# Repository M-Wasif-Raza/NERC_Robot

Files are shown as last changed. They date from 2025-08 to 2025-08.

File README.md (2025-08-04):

# NERC 2024 Indigenous Robot - Autonomous Plantation Robot





🏆 Our team successfully secured first place in the Mini-NERC 2024 competition, demonstrating excellent capabilities in Robotics & Mechatronics doman.

<p align="center">
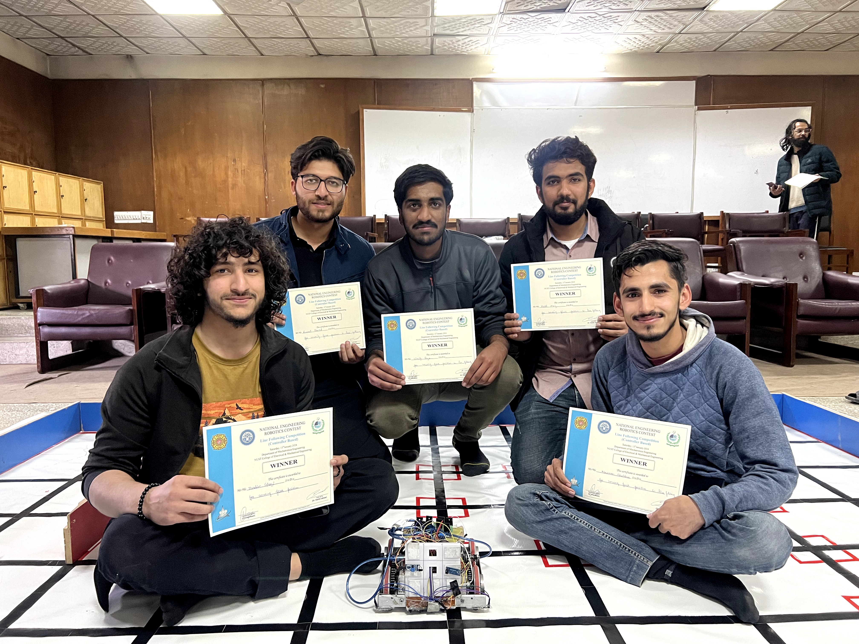
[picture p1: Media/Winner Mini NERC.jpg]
Team Photo
  
  <br/>
  <em>Winning team at Mini-NERC 2024</em>
</p>

<p align="center">
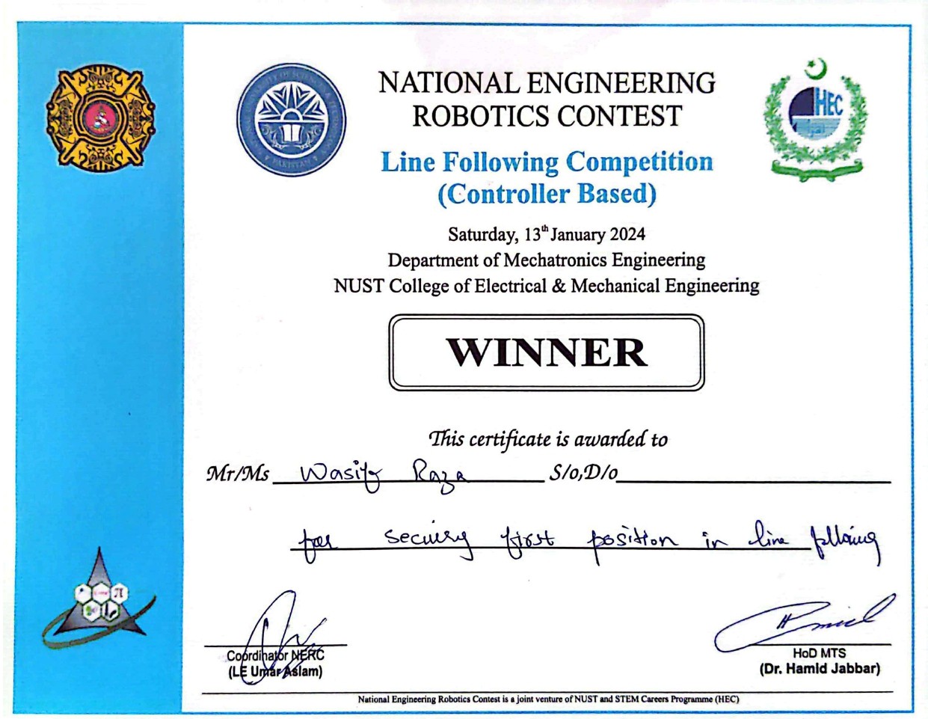
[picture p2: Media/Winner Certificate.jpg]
Winner Certificate
  
  <br/>
  <em>Winner Certificate</em>
</p>

---

##  Project Overview

### National Engineering Robotics Contest (NERC) 2024

The National Engineering Robotics Contest represents a collaborative initiative between the National University of Sciences and Technology (NUST) and the Higher Education Commission's STEM Careers Programme. NERC serves as Pakistan's premier platform for advancing robotics research and fostering innovation in autonomous systems.

### ❓ Problem Statement

The 2024 theme challenged teams to develop an autonomous robot capable of executing a complete tree plantation workflow:

**Primary Objectives:**
- Autonomous navigation through a structured farm environment
- Detection and removal of obstacles (rocks) from designated plantation areas
- Precise placement of trees in prepared soil locations
- Task completion within strict time and accuracy constraints

**Technical Requirements:**
- Fully autonomous operation with no human intervention
- Indigenous design and fabrication of all electronic systems
- Compliance with dimensional and weight specifications
- Integration of multiple sensor systems for navigation and object detection

### 🧱 Arena Specifications

The competition arena simulates a realistic agricultural environment:

- **Grid System**: 12×12 inch precision grid layout
- **Plantation Field**: Dedicated 3×3 grid area for tree placement
- **Dynamic Layout**: Randomized Rock & Tree placement across 9 possible positions
- **Navigation Aids**: Black line pathways and wall-mounted 2D position map

<p align="center">
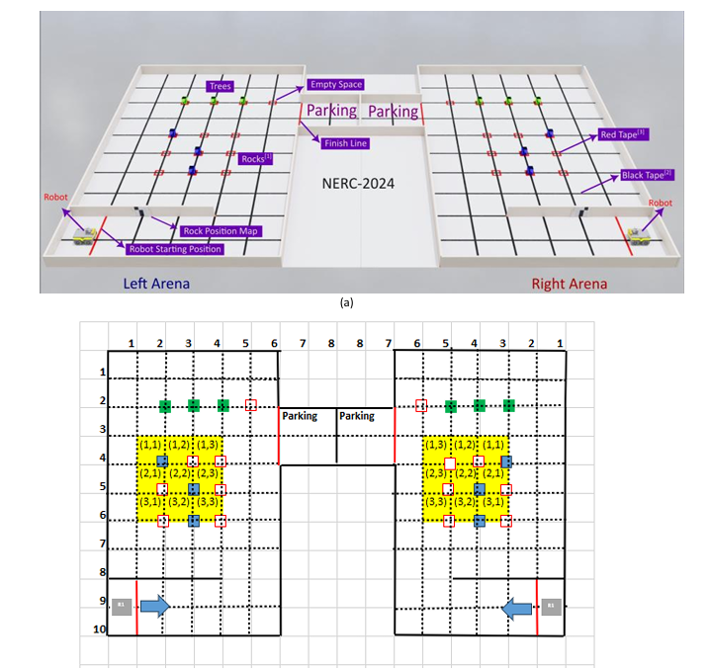
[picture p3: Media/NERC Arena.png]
  
  <br/>
  <em>Competition arena layout</em>
</p>

### 📐 Physical Constraints

| Parameter | Value |
|---|---|
| **Dimensions** | 10" × 10" × Variable Height | 
| **Weight** | < 12 kg | 

📌 For complete information about the competition theme, check [this](/NERC-2024%20Draft1.0.pdf).

---

## 🤖 Robot Overview

### Hardware Design

**Core System Components:**

| Component | Specification | Notes |
|---|---|---|
| **Microcontroller** | Arduino Mega (ATmega2560) | Increased I/O capability, more memory, suitable for complex robotics applications |
| **Sensor Array** | TCRT5000 IR Array (5-channel) | For Line Following |
| **Wheel Motor** | 24V DC Encoder Motors | Differential Drive Configuration |
| **Power System** | 25V LiPo Battery Pack | Alongwith Buck Convertor for Voltage Regulation |
| **Motor Control Circuit** | Custom H-Bridge Design | Indigenous category requirement |
| **Servo Motor** | MG996R Metal Gear Servo Motor | For lifting mechanism |

### Motor Control Circuit Design

The competition required designing a robust H-Bridge motor controller from discrete components.

**Design Specifications:**
- Bidirectional motor control with instant direction reversal
- PWM-based speed regulation
- 3A current capacity
- Arduino-compatible control interface

**Development Process:**
1. **Circuit Analysis**: Theoretical design validation using circuit simulation
2. **Prototype Testing**: Breadboard implementation and performance verification
3. **PCB Design**: Professional circuit board layout using Proteus software
4. **Manufacturing**: Self PCB fabrication and assembly

<p align="center">
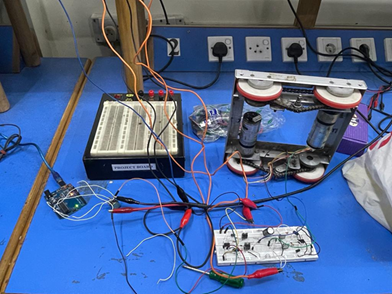
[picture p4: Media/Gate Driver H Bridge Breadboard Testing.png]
  
  <br/>
  <em>Circuit Testing</em>
</p>

### ⚙️ Mechanical System 

Structure of Robot Chassis 

<table align="center">
  <tr>
    <td align="center">
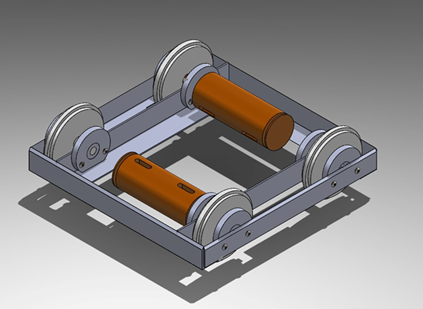
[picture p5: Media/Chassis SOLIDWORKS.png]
      <br/>
    </td>
    <td align="center">
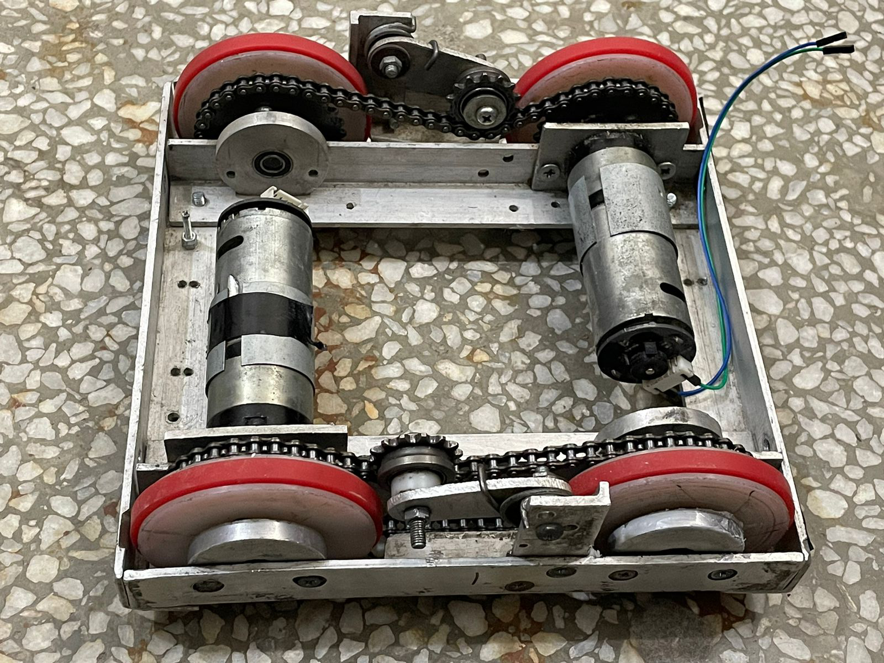
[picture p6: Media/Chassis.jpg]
      <br/>
    </td>
  </tr>
</table>

### 🔋 Power Management System

**Custom Battery Configuration:**
- **Cell Type**: 3.7V Lithium Polymer
- **Configuration**: 7-cell series arrangement (7S1P)
- **Capacity**: 4000mAh
- **Output Voltage**: 25.9V (nominal)

---

## 💻 Coding Development

### Development Process

1. **Hardware Setup**: Pin configuration and sensor/motor interface initialization
2. **Basic Motion Control**: Implementation of fundamental movement functions with encoder feedback
3. **Navigation System**: Development of line-following and turning algorithms using sensor arrays
4. **Task Automation**: Integration of object manipulation functions (pick/drop operations)
5. **System Testing**

### ⚡Function Overview

**Movement Control:**
- `goStraightAlign()`, `goback()`, `stop()` - Basic motion with differential speed control
- `rotateLeft()`, `rotateRight()`, `rotate180()` - Precision turns using encoder feedback
- `turnSlightlyLeft()`, `turnSlightlyRight()` - Line-following trajectory corrections

**Task Functions:**
- `pick()`, `drop()` – Automated manipulation with servo control  
- `map_reading()` – 2D map reading  

<br>

https://github.com/user-attachments/assets/2c020f59-3387-43c8-be6c-983f413f9202

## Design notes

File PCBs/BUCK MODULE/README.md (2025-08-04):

<p align="center">
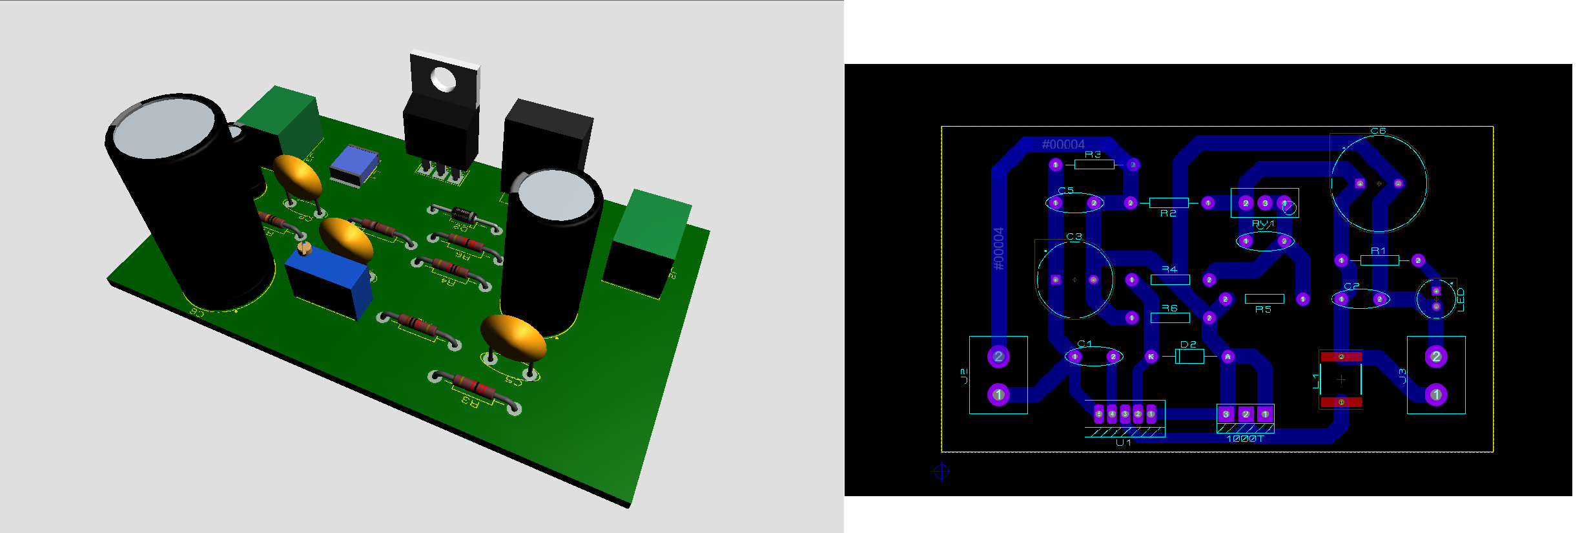
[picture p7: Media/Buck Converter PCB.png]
Winner Certificate
  
</p>

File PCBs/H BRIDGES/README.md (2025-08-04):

## H-Bridge using Gate Driver IC

<p align="center">
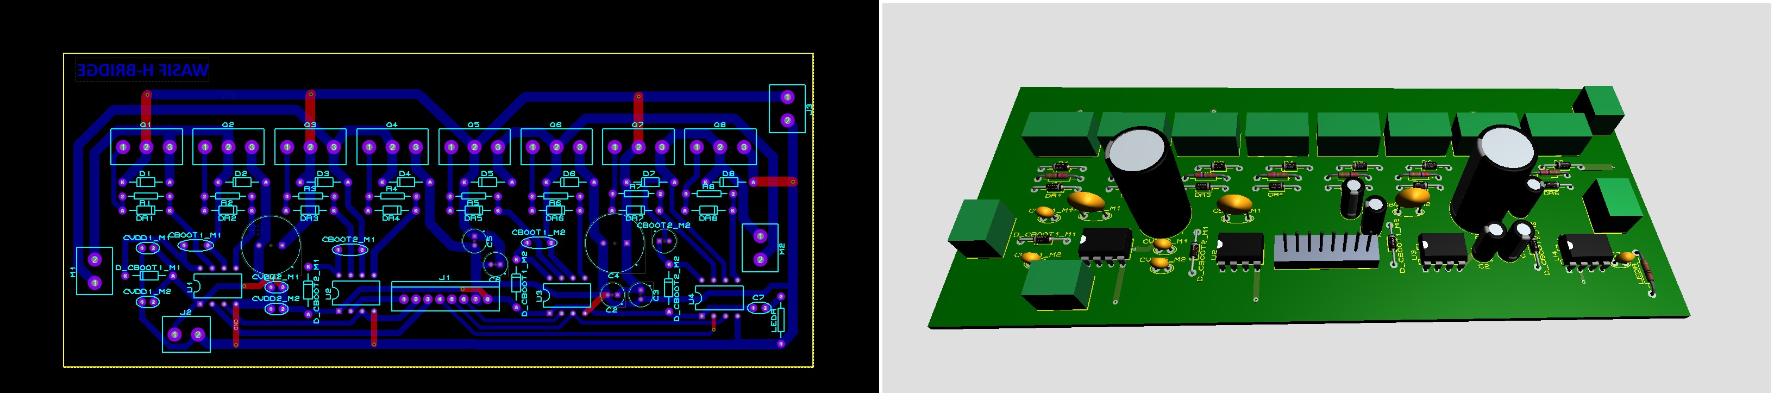
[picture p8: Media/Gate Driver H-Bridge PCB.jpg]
  
</p>
<p align="center">
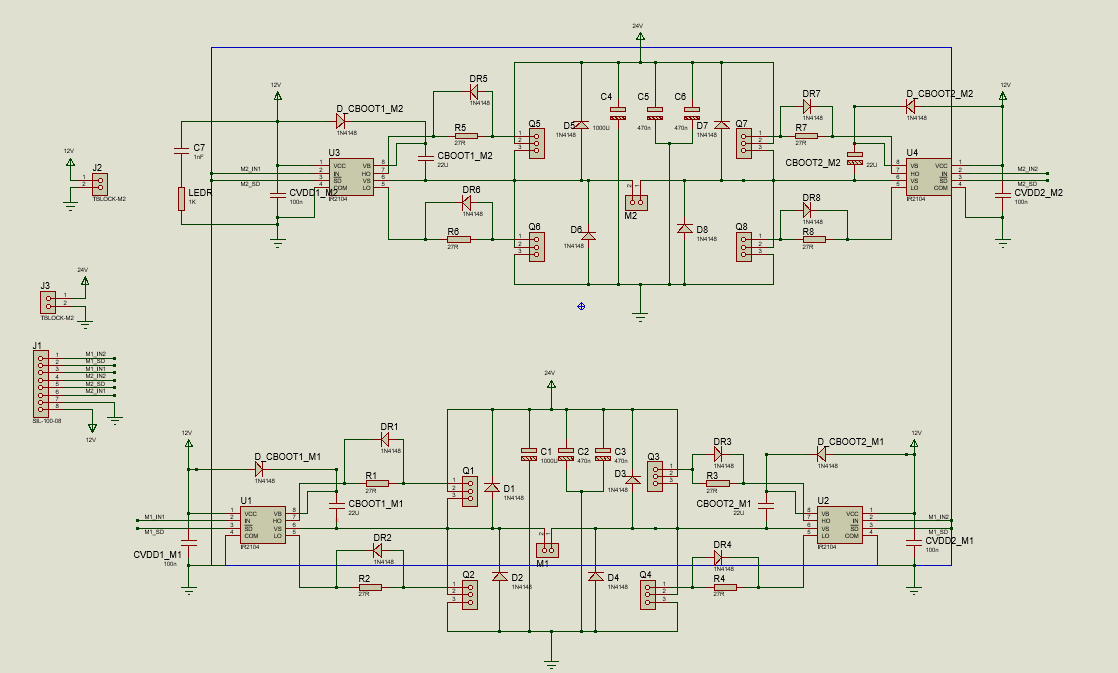
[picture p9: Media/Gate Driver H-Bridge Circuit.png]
  
</p>

## TIP-Based H-Bridge
<p align="center">
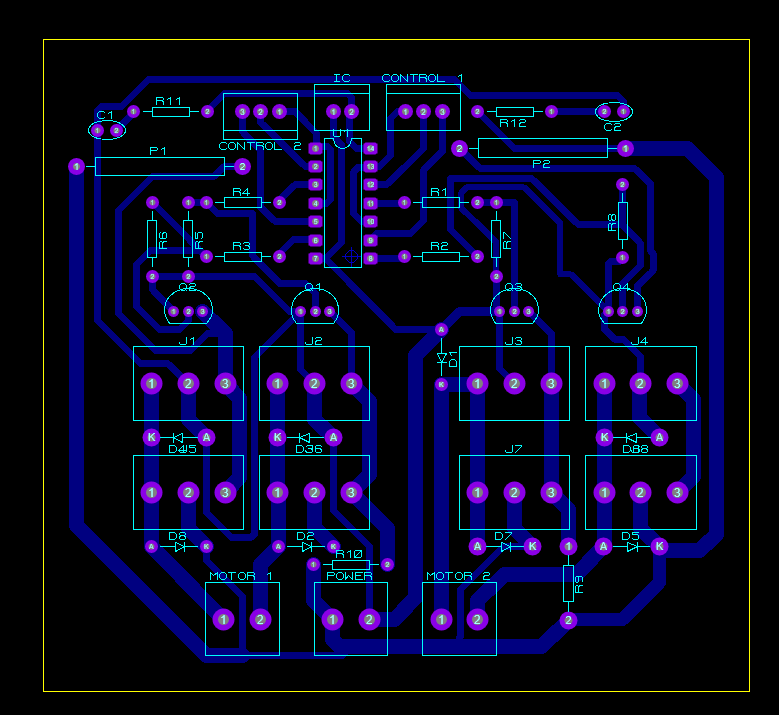
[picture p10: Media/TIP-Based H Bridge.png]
  
</p>

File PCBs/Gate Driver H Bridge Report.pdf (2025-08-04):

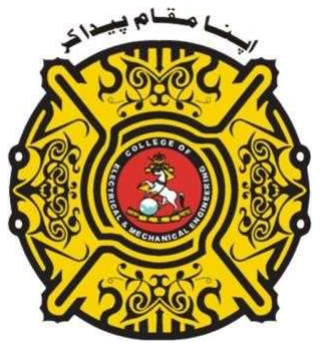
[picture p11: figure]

1

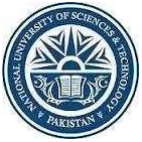
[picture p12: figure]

# Electronic Design Circuit

(EE-313)

# DE-43 Mechatronics Syndicate –B

## Project report

## H-Bridge Motor Driver for 24V, 2-5A DC Motor

## Names:

1. Muhammad Wasif Raza | 385589
2. Rameel Ahmed | 390647
3. Abdul Moiz | 392858

Submitted to: LE Noor ul Huda

2

## Table of Contents

1.Introducon | 1

### 1.1 Background | 2 1.2 Objectives | 3

2.Literature Review | 4
3.Circuit Design | 1

### 3.1 Motor Specifications | 2 3.2 H-Bridge Configuration | 3 3.3 Component Selection | 2 3.4 Power Supply | 3

4.Calculaons | 4

### 4.1 Current Ratings | 5 4.2 Power Dissipation | 6

5.Implementaon | 1

### 5.1 Circuit Assembly | 2 5.2 Testing Procedures | 3

6.Results and Discussion | 4

### 6.1 Experimental Results | 5 6.2 Performance Evaluaon | 6

7.Conclusion | 1
8.Future Work | 4
9.References | 1

3

## 1. Introducon:

### 1.1 Background:

H-Bridge motor drivers are crucial components in electronic systems that require bidireconal control of DC motors. They consist of a configuraon of switches (typically transistors) that enable the motor to move both forward and backward. This flexibility is essenal in applicaons such as robocs, electric vehicles, and industrial automaon.

### 1.2 Objecves:

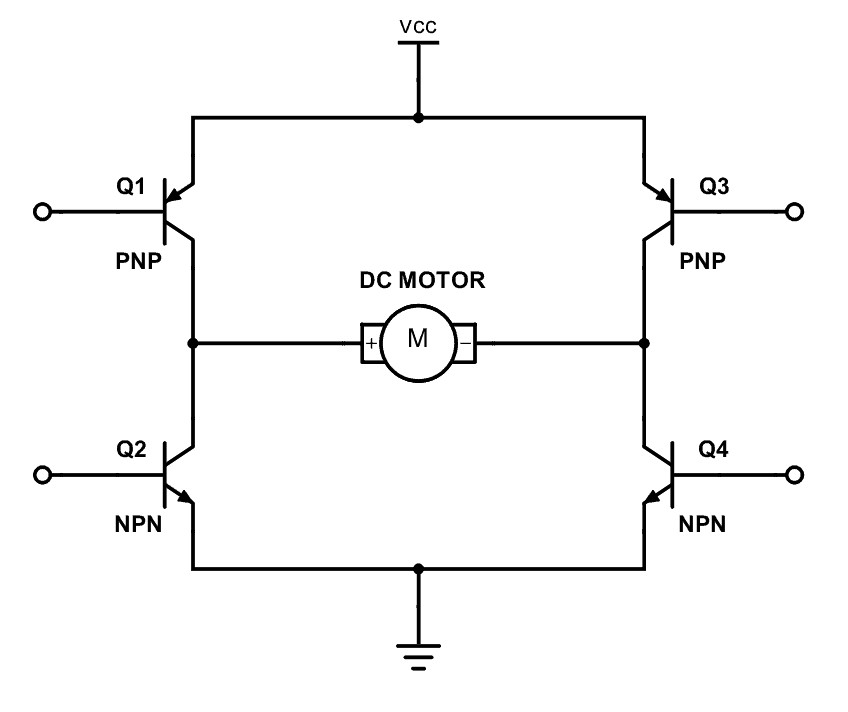
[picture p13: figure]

The primary goal of this project was to design and implement an efficient H-Bridge motor driver capable of controlling a 24V DC motor. The driver should enable bidireconal moon with a current rang suitable for motors ranging from 2 to 5 amperes which we have achieved in this project.

## 2. Literature Review:

H-Bridge motor drivers have been extensively studied and widely applied in various fields. PWM (Pulse Width Modulaon) is oen employed to control motor speed efficiently. MOSFETs are commonly used as switching elements due to their fast-switching speeds and low power consumpon. Safety consideraons involve protecng the circuit from overcurrent and overvoltage condions to prevent damage to the components.

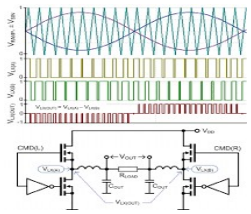
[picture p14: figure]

4

## 3. Circuit Design:

### 3.1 Motor Specificaons:

The 24V DC motor in queson has the following specificaons: operang voltage of 24V, current rang ranging from 2 to 5 amperes, and a power rang of [average=80-120W]. These specificaons will guide the design of the H-Bridge circuit.

### 3.2 H-Bridge Configuraon:

The chosen H-Bridge configuraon involves four MOSFETs arranged in a bridge topology. The schemac diagram illustrates how these components enable bidireconal control of the connected DC motor. Diodes are placed across each MOSFET to handle back-EMF and protect the transistors.

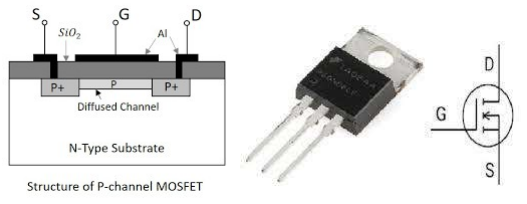
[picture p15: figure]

### 3.3 Component Selecon:

MOSFETs with suitable voltage and current rangs have been selected for this project ([provide specific part numbers]). The diodes should have fast recovery mes to handle the motor's inducve loads effecvely. Addionally, resistors are chosen to set gate drive currents and ensure proper MOSFET switching.

### 1. MOSFETs (Metal-Oxide-Semiconductor Field-Effect Transistors):

- N-channel MOSFETs -4x [IRF-3205]

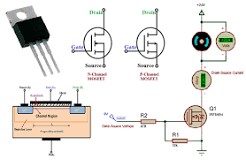
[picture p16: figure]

5

### 2. Diodes:

- Fast-recovery diodes (4x 1N-4148,6x 1N-5819)

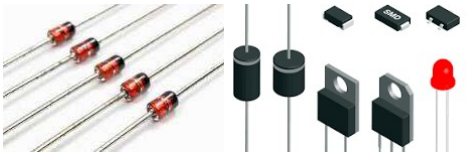
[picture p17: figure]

### 3. Resistors:

- Gate resistors for MOSFETs (4x 27ohm)

### 4. Capacitors:

- Bootstrap capacitors for MOSFET gate drivers [2x 1 uF]

### 5. Power Supply:

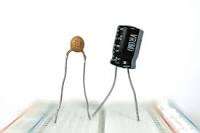
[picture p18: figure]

- Vcc: Power supply for the H-Bridge circuit (Select based on voltage and current requirements)

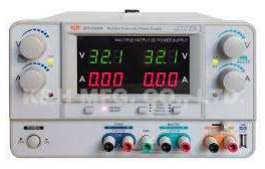
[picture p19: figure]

6

### 6. DC Motor:

- 24V DC Motor with a current rang between 2-5 amperes

### 7. Heat Sink:

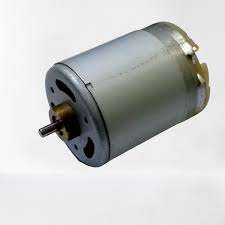
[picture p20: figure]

- Heat sinks for MOSFETs to dissipate heat generated during operaon

### 8. Connectors and Wiring:

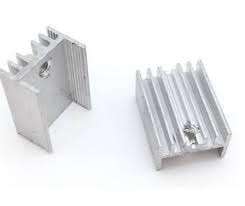
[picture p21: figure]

- Connectors and wiring for power supply, motor connecons, and control signals.

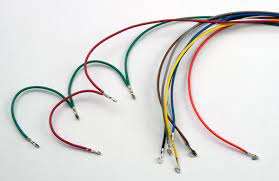
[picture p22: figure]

7

### 9. PCB(Printed Circuit Board)

- PCB to mount and connect all components.

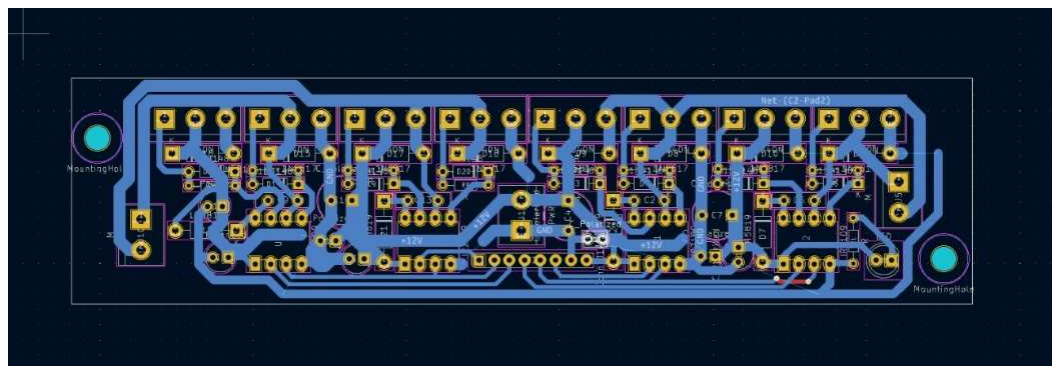
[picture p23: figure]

### 3.4 Power Supply:

The power supply for the H-Bridge circuit must provide a stable voltage in the range of [0-24] V. Consideraons for voltage regulaon and filtering are essenal to maintain stable operaon.

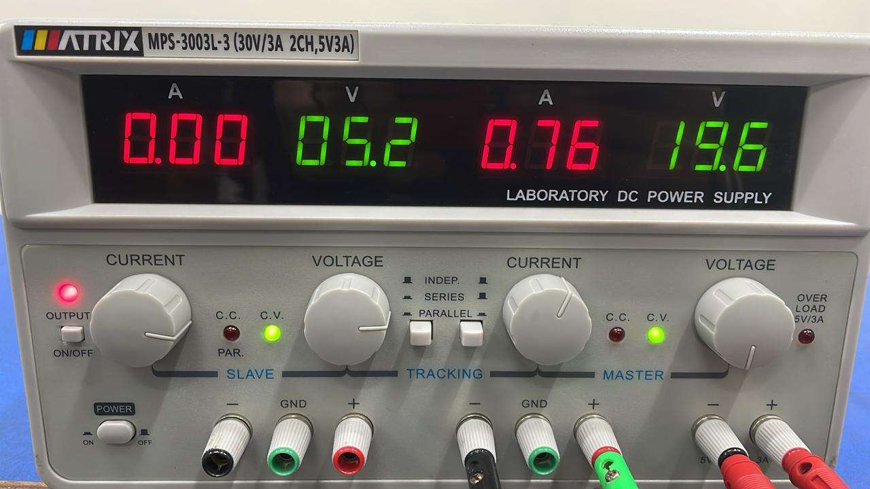
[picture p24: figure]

8

## 4. Calculaons:

### 4.1 Current Rangs:

Calculaons are performed to determine the current rangs of the MOSFETs and diodes. The peak current through each MOSFET is calculated as [2-5]A. Diode currents are evaluated to ensure they can handle the back-EMF generated by the motor.

### 4.2 Power Dissipaon:

Power dissipaon calculaons are crucial for determining the thermal requirements of the MOSFETs and diodes. This involves evaluang the power dissipated during the ON and OFF states of the transistors.

## 5. Implementaon:

### 5.1 Circuit Assembly:

Follow these steps to assemble the H-Bridge circuit:
1. Place the MOSFETs and diodes on the PCB according to the schemac.
2. Connect the gate, source, and drain terminals of the MOSFETs appropriately.
3. Ensure proper placement of diodes to handle back-EMF.
4. Connect the power supply and motor as per the schemac.

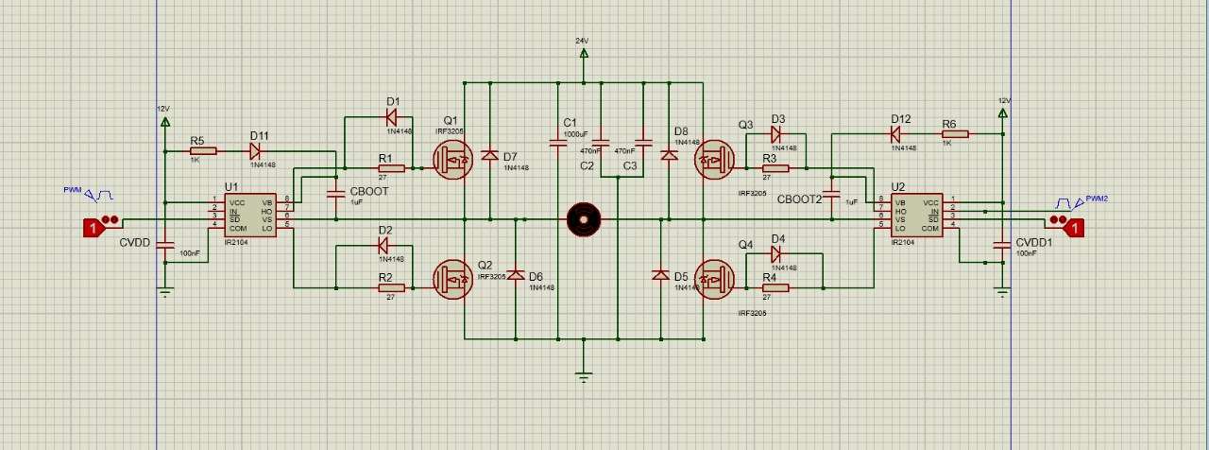
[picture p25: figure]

### 5.2 Tesng Procedures:

Tesng involves the following steps:
1. Apply power and verify that there are no short circuits.
2. Test forward and reverse moon using PWM for speed control.
3. Monitor current and voltage waveforms on an oscilloscope.
4. Ensure that the driver operates within safe temperature limits.

9

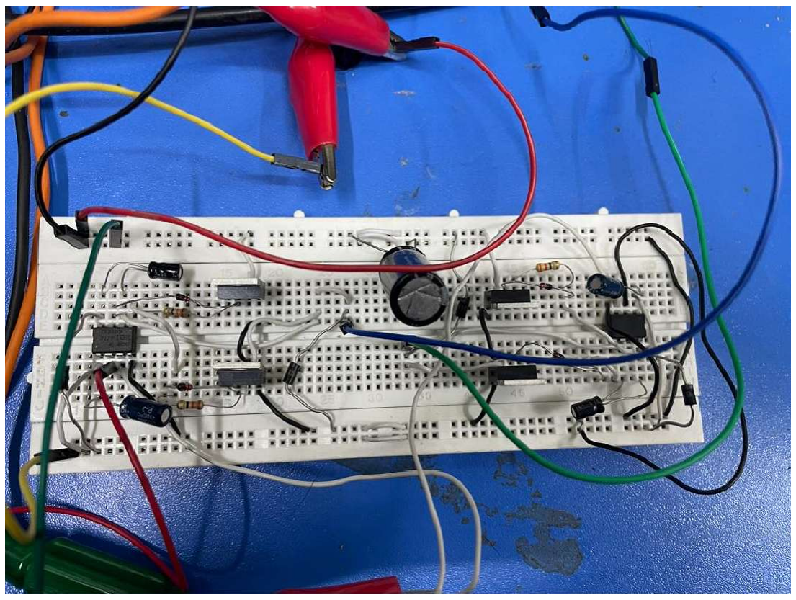
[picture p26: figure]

## 6. Results and Discussion:

### 6.1 Experimental Results:

Experimental results confirm the successful bidireconal control of the 24V DC motor. Speed control using PWM is effecve, and the driver operates within the specified current limits. Voltage and current waveforms exhibit expected behaviours.

### 6.2 Performance Evaluaon:

The H-Bridge motor driver performs well, meeng the project objecves. The efficiency of the bidireconal control and the ability to handle the specified current range are confirmed. Comparisons between theorecal calculaons and experimental results show good agreement.

## 7. Conclusion:

In conclusion, the designed H-Bridge motor driver effecvely controls a 24V DC motor bidireconally. The project has successfully achieved its objecves, providing a reliable and efficient soluon for applicaons requiring versale motor control.

10

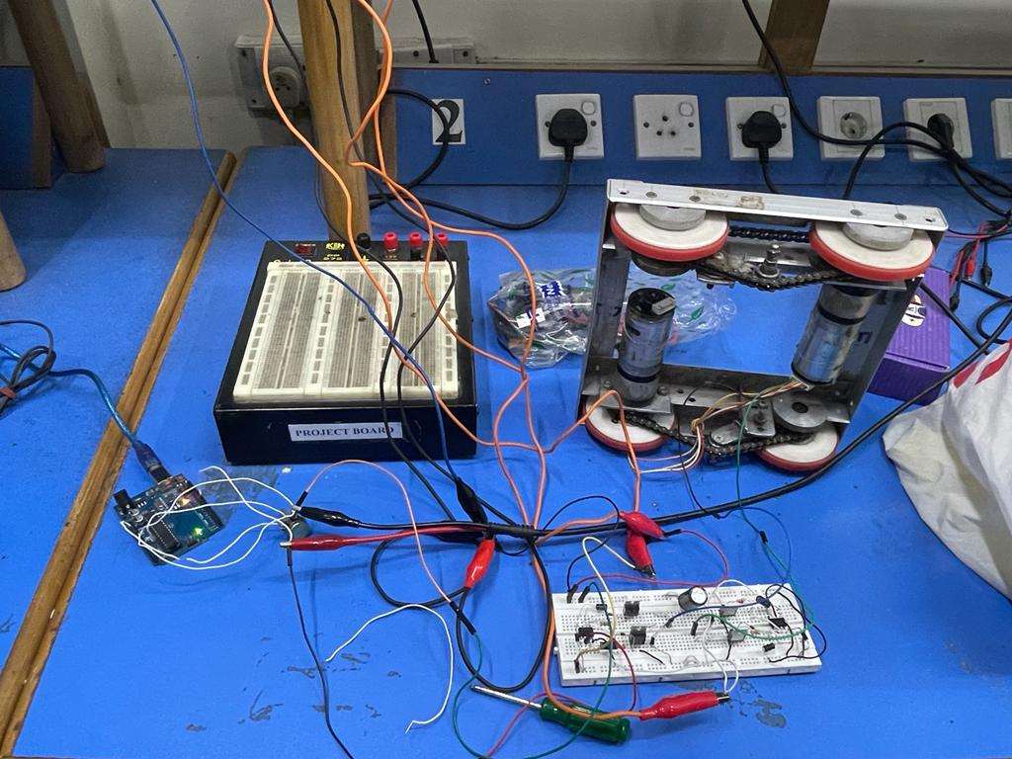
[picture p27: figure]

## 8. Future Work:

Potenal areas for improvement include making a dual pcb on a single board.

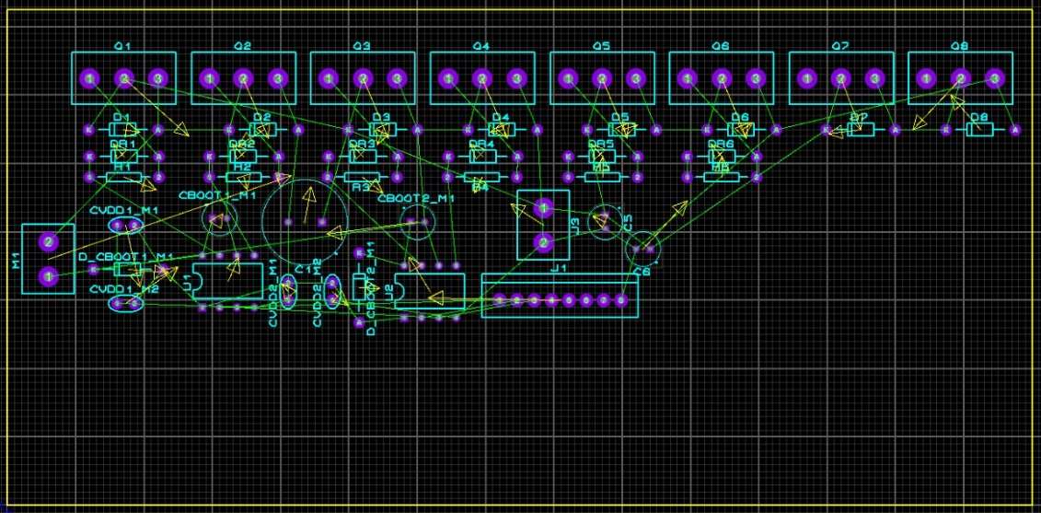
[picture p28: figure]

## 9. References:

### 1. hps://www..com/lit/an/slua887a/slua887a.pdf?ts=1701760089734&ref_url=hps%253

A%252F%252Fwww.google.com%252F

### 2. hps://pdf1.alldatasheet.com/datasheet-pdf/view/398486/IRF/IR2109.html 3. hps://www.hindawi.com/journals/je/2022/2273819/

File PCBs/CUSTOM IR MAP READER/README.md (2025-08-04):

<p align="center">
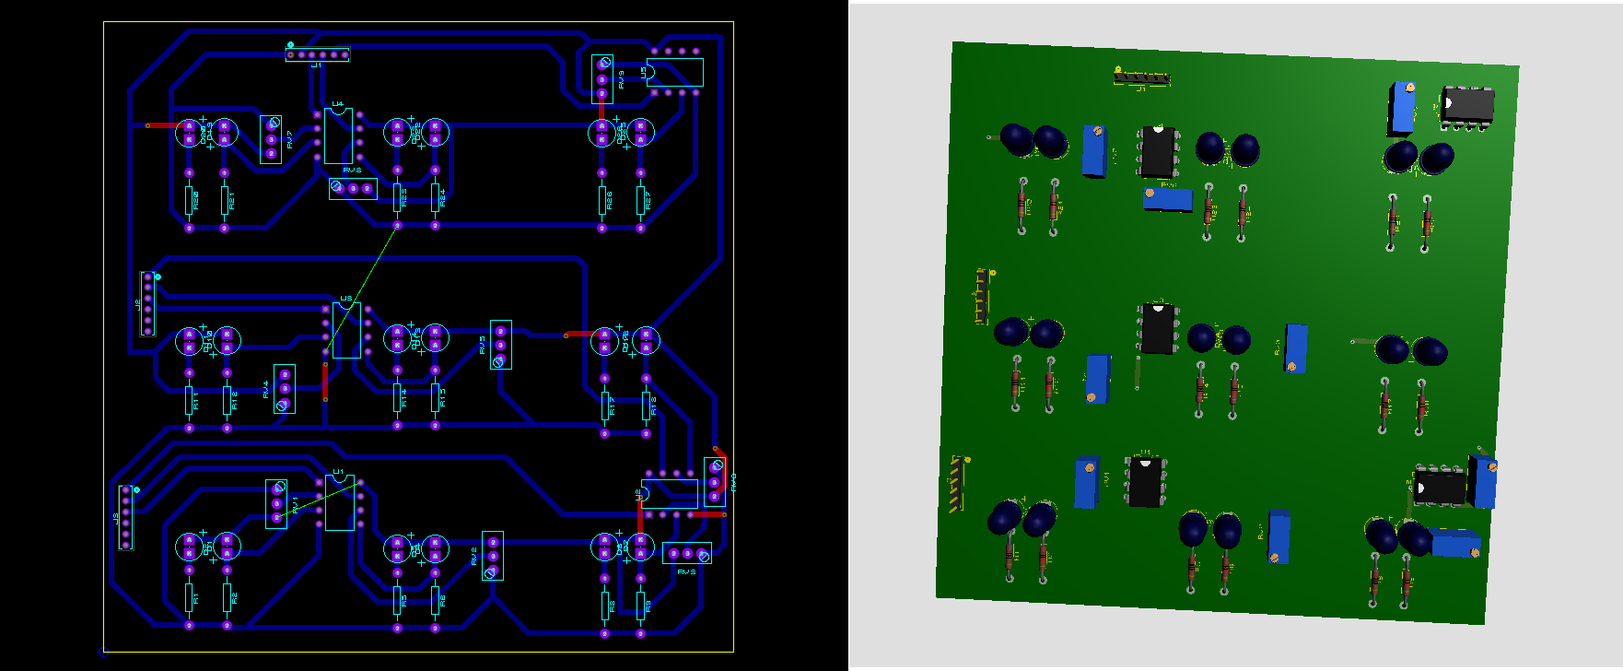
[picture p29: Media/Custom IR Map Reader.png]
Winner Certificate
  
</p>

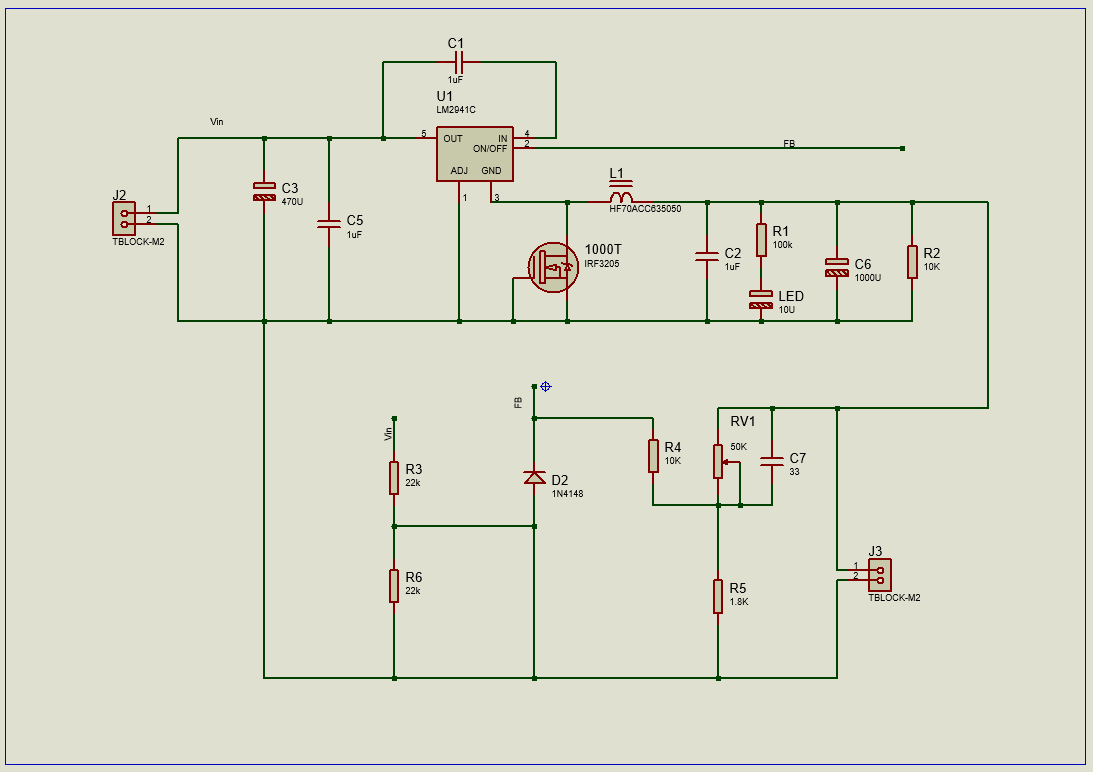
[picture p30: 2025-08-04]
Media/Buck Converter Circuit.png

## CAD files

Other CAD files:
PCBs/CUSTOM IR MAP READER/SOLIDWORKS FILE/Board.SLDPRT

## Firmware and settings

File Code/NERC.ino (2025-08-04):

#include <Encoder.h>
#include <Servo.h>

Servo myservo; 
int pos = 65;
// Define the pins for the encoders
#define ENCODER1_A 2
#define ENCODER1_B 5
#define ENCODER2_A 3
#define ENCODER2_B 4

// Define the pins for the motor control
#define L_in1 42// LEFT MOTOR
#define L_in2 43 // LEFT MOTOR reverse
#define R_in1 40 // right MOTOR
#define R_in2 41// RIGHT MOTOR reverse
#define LEFT_Motor_PWM 7
#define RIGHT_Motor_PWM 6

// Define the pins for the sensors
#define MS 23 // right MOTOR
#define RS 24
#define RRS 25
#define LS 26
#define LLS 27
#define S1 28
#define S2 29
#define LBACK 36
#define RBACK 37
#define LMBACK 34
#define RMBACK 35

int map_arr[] = {48,46,47,
                 49,51,50};
                 
int map_arr_value[6];

int pulsel=0;
int pulser=0;
// Create instances of the Encoder class
Encoder encoder1(ENCODER1_A, ENCODER1_B);
Encoder encoder2(ENCODER2_A, ENCODER2_B);
int counter= -2;
int lspd=160;
int rspd=160;
int ll=210;
int rr=210;
int stop_forward_speed=110;

void setup() 
{ // Set motor control pins as outputs
  Serial.begin(9600);
  pinMode(R_in1, OUTPUT);
  pinMode(L_in2, OUTPUT);
  pinMode(R_in2, OUTPUT);
  pinMode(L_in1, OUTPUT);
  pinMode(LEFT_Motor_PWM, OUTPUT);
  pinMode(RIGHT_Motor_PWM, OUTPUT);
  // Set all of the sensor pins to inputs
  pinMode(LS, INPUT);
  pinMode(LLS, INPUT);
  pinMode(RS, INPUT);
  pinMode(RRS, INPUT);
  pinMode(MS,INPUT);
  pinMode(S1,INPUT);
  pinMode(S2,INPUT);
  pinMode(RBACK,INPUT);
  pinMode(LBACK,INPUT);
  for(int i = 0;i<6;i++)
  {
    pinMode(map_arr[i],INPUT);
  }
  myservo.attach(10);
  // Servo is stationary.
  myservo.write(100);
}

void rotate180(int a, int b)
{
  stop();
  delay(500);
// Move motor 1 forward
  encoder1.write(0);
  encoder2.write(0);
  int encoder_L = encoder2.read();
  int encoder_R = encoder1.read();
  int middleSensor = digitalRead(MS);

  while(encoder_R<2050&&encoder_L>-2050)
  {
    digitalWrite(R_in2, LOW);
    digitalWrite(R_in1,HIGH);
    digitalWrite(L_in2, HIGH);
    digitalWrite(L_in1, LOW);
    analogWrite(LEFT_Motor_PWM, a);
    analogWrite(RIGHT_Motor_PWM, b);
    encoder_L = encoder2.read();
    encoder_R = encoder1.read();
  }
  while(encoder_L>-2050)
  {
    digitalWrite(R_in2, LOW);
    digitalWrite(R_in1,LOW);
    digitalWrite(L_in2,HIGH);
    digitalWrite(L_in1, LOW);
    analogWrite(LEFT_Motor_PWM, a);
    analogWrite(RIGHT_Motor_PWM, b);
    encoder_L = encoder2.read();
    encoder_R = encoder1.read();
  }
  while(encoder_R<2050)
  {
    digitalWrite(R_in2, LOW);
    digitalWrite(R_in1,HIGH);
    digitalWrite(L_in2, LOW);
    digitalWrite(L_in1, LOW);
    analogWrite(LEFT_Motor_PWM, a);
    analogWrite(RIGHT_Motor_PWM, b);
    encoder_L = encoder2.read();
    encoder_R = encoder1.read();
  }

  pulsel=encoder1.read();
  pulser=encoder2.read();
  Serial.print("Pulse left Count: " );
  Serial.println(pulsel);
  Serial.print("Pulse right Count: " );
  Serial.println(pulser);
  encoder1.write(0);
  encoder2.write(0);
   encoder_L = encoder2.read();
   encoder_R = encoder1.read();
  
  while(encoder_L<50 && encoder_R<50 )
  {
    digitalWrite(R_in2, LOW);
    digitalWrite(R_in1, HIGH);
    digitalWrite(L_in2, LOW);
    digitalWrite(L_in1, HIGH);
    analogWrite(LEFT_Motor_PWM, stop_forward_speed);
    analogWrite(RIGHT_Motor_PWM, stop_forward_speed);
    encoder_L = encoder2.read();
    encoder_R = encoder1.read();
  }
  stop();  
}

void rotateRight11(int a, int b)
{
  stop();
  delay(300);

  encoder1.write(0);
  encoder2.write(0);
  int encoder_L = encoder2.read();
  int encoder_R = encoder1.read();
  
  while(encoder_L<250 && encoder_R<250)
  {
    digitalWrite(R_in2, LOW);
    digitalWrite(R_in1, HIGH);
    digitalWrite(L_in2, LOW);
    digitalWrite(L_in1, HIGH);
    analogWrite(LEFT_Motor_PWM, stop_forward_speed);
    analogWrite(RIGHT_Motor_PWM, stop_forward_speed);
    encoder_L = encoder2.read();
    encoder_R = encoder1.read();
  }

  encoder1.write(0);
  encoder2.write(0);
  encoder_L = encoder2.read();
  encoder_R = encoder1.read();
  int rightSensor = digitalRead(RS);

  while(encoder_L<1050 && encoder_R>-950 )
  {
    digitalWrite(R_in2, HIGH);
    digitalWrite(R_in1, LOW);
    digitalWrite(L_in2, LOW);
    digitalWrite(L_in1, HIGH);
    analogWrite(LEFT_Motor_PWM, a);
    analogWrite(RIGHT_Motor_PWM, b);
    encoder_L = encoder2.read();
    encoder_R = encoder1.read();
    rightSensor = digitalRead(RS);
  }
  while(encoder_R>-950 )
  {
    digitalWrite(R_in2, HIGH);
    digitalWrite(R_in1, LOW);
    digitalWrite(L_in2, LOW);
    digitalWrite(L_in1, LOW);
    analogWrite(LEFT_Motor_PWM, a);
    analogWrite(RIGHT_Motor_PWM, b);
    encoder_L = encoder2.read();
    encoder_R = encoder1.read();
  }
  while(encoder_L<1050)
  {
    digitalWrite(R_in2, LOW);
    digitalWrite(R_in1, LOW);
    digitalWrite(L_in2, LOW);
    digitalWrite(L_in1, HIGH);
    analogWrite(LEFT_Motor_PWM, a);
    analogWrite(RIGHT_Motor_PWM, b);
    encoder_L = encoder2.read();
    encoder_R = encoder1.read();
  }
  stop();
  pulser=encoder1.read();
  pulsel=encoder2.read();
  Serial.print("Pulse left Count: " );
  Serial.println(pulsel);
  Serial.print("Pulse right Count: " );
  Serial.println(pulser);
}

void rotateRight(int a, int b)
{
  stop();
  delay(350);
  int L_MS = digitalRead(S1);
  int R_MS = digitalRead(S2);
  
  while(R_MS==1 && L_MS == 1)
  {
    goStraightAlign(stop_forward_speed,stop_forward_speed);
    L_MS = digitalRead(S1);
    R_MS = digitalRead(S2);
  }

  encoder1.write(0);
  encoder2.write(0);
  int encoder_L = encoder2.read();
  int encoder_R = encoder1.read();
  
  /*while(encoder_L<10 && encoder_R<10 )
  {
    digitalWrite(R_in2, LOW);
    digitalWrite(R_in1, HIGH);
    digitalWrite(L_in2, LOW);
    digitalWrite(L_in1, HIGH);
    analogWrite(LEFT_Motor_PWM, stop_forward_speed);
    analogWrite(RIGHT_Motor_PWM, stop_forward_speed);
    encoder_L = encoder2.read();
    encoder_R = encoder1.read();
  }*/

  encoder1.write(0);
  encoder2.write(0);
  encoder_L = encoder2.read();
  encoder_R = encoder1.read();
  int rightSensor = digitalRead(RS);

  while(encoder_L<500 && encoder_R>-500 )
  {
    digitalWrite(R_in2, HIGH);
    digitalWrite(R_in1, LOW);
    digitalWrite(L_in2, LOW);
    digitalWrite(L_in1, HIGH);
    analogWrite(LEFT_Motor_PWM, a);
    analogWrite(RIGHT_Motor_PWM, b);
    encoder_L = encoder2.read();
    encoder_R = encoder1.read();
    rightSensor = digitalRead(RS);
  }
  while(rightSensor == 1)
  {
    digitalWrite(R_in2, HIGH);
    digitalWrite(R_in1, LOW);
    digitalWrite(L_in2, LOW);
    digitalWrite(L_in1, HIGH);
    analogWrite(LEFT_Motor_PWM, a);
    analogWrite(RIGHT_Motor_PWM, b);
    rightSensor = digitalRead(RS);
  }

  stop();
  pulser=encoder1.read();
  pulsel=encoder2.read();
  Serial.print("Pulse left Count: " );
  Serial.println(pulsel);
  Serial.print("Pulse right Count: " );
  Serial.println(pulser);
}

void rotateLeft(int a, int b)
{
  stop();
  delay(300);
  int L_MS = digitalRead(S1);
  int R_MS = digitalRead(S2);
  
  while(R_MS==1 && L_MS == 1)
  {
    L_MS = digitalRead(S1);
    R_MS = digitalRead(S2);
    goStraightAlign(stop_forward_speed,stop_forward_speed);
  }
  encoder1.write(0);
  encoder2.write(0);
  int encoder_L = encoder2.read();
  int encoder_R = encoder1.read();
  
  while(encoder_R<1010 && encoder_L>-930)
  {
    digitalWrite(R_in2, LOW);
    digitalWrite(R_in1, HIGH);
    digitalWrite(L_in2, HIGH);
    digitalWrite(L_in1, LOW);
    analogWrite(LEFT_Motor_PWM, a+20);
    analogWrite(RIGHT_Motor_PWM, b);
    encoder_L = encoder2.read();
    encoder_R = encoder1.read();
  }
  while(encoder_L>-930)
  {
    digitalWrite(R_in2, LOW);
    digitalWrite(R_in1, LOW);
    digitalWrite(L_in2, HIGH);
    digitalWrite(L_in1, LOW);
    analogWrite(LEFT_Motor_PWM, a);
    analogWrite(RIGHT_Motor_PWM, b);
    encoder_L = encoder2.read();
    encoder_R = encoder1.read();
  }
  while(encoder_R<1010)
  {
    digitalWrite(R_in2, LOW);
    digitalWrite(R_in1, HIGH);
    digitalWrite(L_in2, LOW);
    digitalWrite(L_in1, LOW);
    analogWrite(LEFT_Motor_PWM, a);
    analogWrite(RIGHT_Motor_PWM, b);
    encoder_L = encoder2.read();
    encoder_R = encoder1.read();
  }  
  stop();
  pulser=encoder1.read();
  pulsel=encoder2.read();
  Serial.print("Pulse left Count: " );
  Serial.println(pulsel);
  Serial.print("Pulse right Count: " );
  Serial.println(pulser);
}

void stop()
{
  digitalWrite(R_in2, LOW);
  digitalWrite(R_in1, LOW);
  digitalWrite(L_in2, LOW);
  digitalWrite(L_in1, LOW);
  analogWrite(LEFT_Motor_PWM, 0);
  analogWrite(RIGHT_Motor_PWM, 0);
}

void goStraightAlign(int a, int b) 
{
  digitalWrite(R_in2, LOW);
  digitalWrite(R_in1, HIGH);
  digitalWrite(L_in2, LOW);
  digitalWrite(L_in1, HIGH);
  analogWrite(LEFT_Motor_PWM, a);
  analogWrite(RIGHT_Motor_PWM, b);
}
void goback(int a, int b) 
{
  digitalWrite(R_in2, HIGH);
  digitalWrite(R_in1, LOW);
  digitalWrite(L_in2, HIGH);
  digitalWrite(L_in1, LOW);
  analogWrite(LEFT_Motor_PWM, a);
  analogWrite(RIGHT_Motor_PWM, b);
}

void goback1(int a, int b, int encoder_L_value, int encoder_R_value) 
{
  encoder1.write(0);
  encoder2.write(0);
  int encoder_L = encoder2.read();
  int encoder_R = encoder1.read();

  while(encoder_L> encoder_L_value && encoder_R> encoder_R_value)
  {
    digitalWrite(R_in2, HIGH);
    digitalWrite(R_in1, LOW);
    digitalWrite(L_in2, HIGH);
    digitalWrite(L_in1, LOW);
    analogWrite(LEFT_Motor_PWM, a);
    analogWrite(RIGHT_Motor_PWM, b);
    encoder_L = encoder2.read();
    encoder_R = encoder1.read();
  }
  stop();
  pulser=encoder1.read();
  pulsel=encoder2.read();
  Serial.print("Pulse left Count: " );
  Serial.println(pulsel);
  Serial.print("Pulse right Count: " );
  Serial.println(pulser);
}

void turnSlightlyLeft(int a, int b) 
{
  digitalWrite(R_in2, LOW);
  digitalWrite(R_in1, HIGH);
  digitalWrite(L_in2, LOW);
  digitalWrite(L_in1, HIGH);
  analogWrite(LEFT_Motor_PWM, a); 
  analogWrite(RIGHT_Motor_PWM, b); 
}

void turnSlightlyRight(int a, int b)
{
  digitalWrite(R_in2, LOW);
  digitalWrite(R_in1, HIGH);
  digitalWrite(L_in2, LOW);
  digitalWrite(L_in1, HIGH);
  analogWrite(LEFT_Motor_PWM, a); 
  analogWrite(RIGHT_Motor_PWM, b); 
}

void pick()
{
  myservo.write(0);
  delay(300);
  int L_BS = digitalRead(LBACK);
  int R_BS = digitalRead(RBACK); 
  while(L_BS == 1 && R_BS ==1 )
  {
    int leftSensor = digitalRead(LS);
    int rightSensor = digitalRead(RS);
    leftSensor = !leftSensor;
    rightSensor = !rightSensor;

    if (leftSensor == 0  && rightSensor == 0) 
    {  
        goStraightAlign(stop_forward_speed,stop_forward_speed);
    }
    else if (leftSensor==0 && rightSensor ==1 )
    {   
        turnSlightlyRight(lspd+20,0);
    }
          
    else if (leftSensor==1 && rightSensor ==0 )
    {
        turnSlightlyLeft(0,rspd+20);
    }
    else
    {
        goStraightAlign(stop_forward_speed,stop_forward_speed);
    }
    L_BS = digitalRead(LBACK);
    R_BS = digitalRead(RBACK);
  }
  stop();
  delay(300);
  myservo.write(pos);
  delay(600);
}

void drop() 
{
  int L_BS = digitalRead(LBACK);
  int R_BS = digitalRead(RBACK); 
  while(L_BS==1 && R_BS==1 )
  {
    int leftSensor = digitalRead(LS);
    int rightSensor = digitalRead(RS);
    leftSensor = !leftSensor;
    rightSensor = !rightSensor;
    if (leftSensor == 0  && rightSensor == 0) 
    {  
        goStraightAlign(stop_forward_speed,stop_forward_speed);
    }
    else if (leftSensor==0 && rightSensor ==1 )
    {   
        turnSlightlyRight(lspd+20,0);
    }
    else if (leftSensor==1 && rightSensor ==0 )
    {
        turnSlightlyLeft(0,rspd+20);
    }
    else
    {
        goStraightAlign(stop_forward_speed,stop_forward_speed);
    }
    L_BS = digitalRead(LBACK);
    R_BS = digitalRead(RBACK);
  }
  stop();
  delay(300);
  int i = 60;
  for (i = 60; i > 0; i-=4)
  {
      myservo.write(i);
      delay(80);
  }
  delay(300);
}

void map_reading()
{
  stop();
  delay(150);
  int a = 0;
  while (a < 2)
  {
    if (a == 0)
    {
      encoder1.write(0);
      encoder2.write(0);
      int encoder_L = encoder2.read();
      int encoder_R = encoder1.read();
      while(encoder_L<600 && encoder_R<600)
      {
        int leftSensor = digitalRead(LS);
        int rightSensor = digitalRead(RS);
        leftSensor = !leftSensor;
        rightSensor = !rightSensor;
        if (leftSensor == 0  && rightSensor == 0) 
        {  
            goStraightAlign(stop_forward_speed,stop_forward_speed);
        }
        else if (leftSensor==0 && rightSensor ==1 )
        {   
            turnSlightlyRight(lspd+20,0);
        }
        else if (leftSensor==1 && rightSensor ==0 )
        {
            turnSlightlyLeft(0,rspd+20);
        }
        else
        {
            goStraightAlign(stop_forward_speed,stop_forward_speed);
        }
        encoder_L = encoder2.read();
        encoder_R = encoder1.read();
      }
      stop();
    }
    if (a==1)
    {
      int L_BS = digitalRead(LBACK);
      int R_BS = digitalRead(RBACK); 
      while(L_BS == 1 && R_BS ==1 )
      {
        int leftSensor = digitalRead(LS);
        int rightSensor = digitalRead(RS);
        leftSensor = !leftSensor;
        rightSensor = !rightSensor;

        if (leftSensor == 0  && rightSensor == 0) 
        {  
            goStraightAlign(stop_forward_speed,stop_forward_speed);
        }
        else if (leftSensor==0 && rightSensor ==1 )
        {   
            turnSlightlyRight(lspd+20,0);
        }
              
        else if (leftSensor==1 && rightSensor ==0 )
        {
            turnSlightlyLeft(0,rspd+20);
        }
        else
        {
            goStraightAlign(stop_forward_speed,stop_forward_speed);
        }
        L_BS = digitalRead(LBACK);
        R_BS = digitalRead(RBACK);
      }
      stop();
      
    }

    encoder1.write(0);
    encoder2.write(0);
    int encoder_L = encoder2.read();
    int encoder_R = encoder1.read();
    
    while(encoder_L>-1150 && encoder_R>-1150 )
    {
      
      int leftSensor = digitalRead(LMBACK);
      int leftMostSensor = digitalRead(LBACK);
      int rightSensor = digitalRead(RMBACK);
      int rightMostSensor = digitalRead(RBACK);
      
      leftSensor = !leftSensor;
      leftMostSensor = !leftMostSensor;
      rightSensor = !rightSensor;
      rightMostSensor = !rightMostSensor;

      if (leftSensor == 0  && rightSensor == 0 && leftMostSensor==0 && rightMostSensor ==0) 
      {  
        goback(stop_forward_speed,stop_forward_speed);
      }
      else if (leftSensor==0 && rightSensor ==1 )
      {   
        goback(0,rspd+10);
      }
            
      else if (leftSensor==1 && rightSensor ==0 )
      {
        goback(lspd+10,0);
      }
      
      else if (leftMostSensor==1 && rightSensor ==0 )
      { 
        goback(lspd+30,0);
      }
      else if (leftSensor==0 && rightMostSensor ==1 )
      {  
        goback(0,rspd+30);
      }
      else
      {
        goback(stop_forward_speed,stop_forward_speed);
      }
      encoder_L = encoder2.read();
      encoder_R = encoder1.read();
    }
    stop();
    delay(300);
    a++;
  }
  for(int i = 0; i<6; i++)
    {
      map_arr_value[i] = !digitalRead(map_arr[i]);
      Serial.print(map_arr_value[i]);
    }
}
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
